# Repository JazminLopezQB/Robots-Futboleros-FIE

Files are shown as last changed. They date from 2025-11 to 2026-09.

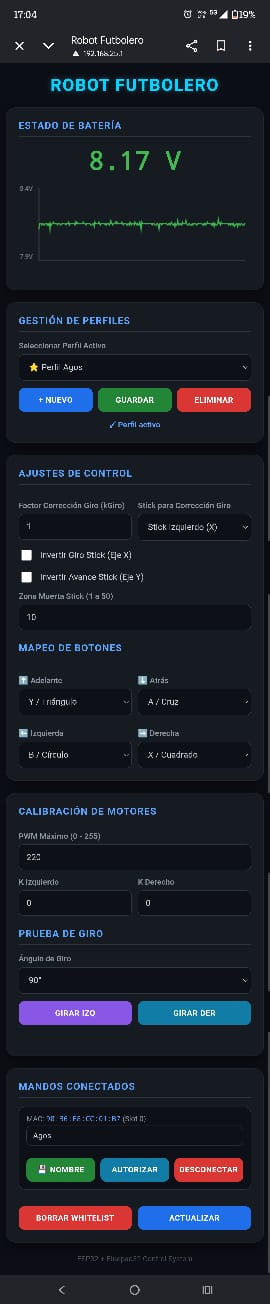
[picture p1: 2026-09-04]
Código_Agos_BLUEPAD32/APyWEB_Actual.jpeg

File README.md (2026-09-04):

# Robots Futboleros de la FIE

---
## Instrucciones de Uso con CÓDIGO VIEJO

### Conectar Mando Bluetooth a Robot

#### 1) Conseguir la MAC Adress de la ESP usada:
  1. Activar el Bluetooth de la ESP.
  2. Descargar la siguiente aplicación en el celular.
  3. Vincularse desde el celular a la ESP con Bluetooth.
  4. Abrir la aplicación y dirigirse a la sección de dispositivos.
  5. En dicha sección debería aparecer la ESP con su MAC Adress.

#### 2) Grabar la MAC Adress correcta al mando:
  1. Descargar e instalar SixaxisPairTool.
  2. Abrir la aplicación y conectar el mando a la computadora mediante un cable USB.
  3. Si es la primera vez que se conecta el mando, se descargarán e instalarán los drivers adecuados.
  4. Una vez finalizado el proceso, en la aplicación meter la MAC Adress de la ESP y darle a actualizar.
  5. Corroborar.

### Mantenimiento de Baterias

- Para controlar el nivel de las baterías:
  - Medir con multimetro en los pines VCC y GND de los puentes H o en la bornera en caso de tener una.
  - La tensión minima es de 6,5V y la máxima de 8,4V

- Para mantener:
  - En caso de que la tensión sea mínima, retirar las baterias y cargar adecuadamente.
  - Al reponer las baterias, reforzar y homologar.

### Tips Generales

- En caso de que el robot sufra una contusión y se reinicie, presionar el boton de conexión de el mando para reestablecer el enlace entre ambos.
- Presionando el panel tactil de los mandos de PS4 se puede determinar su nivel de bateria según cuanto vibren.

---
---
## Bluepad32 ESP32

**Links Útiles:** ^43a2ae
- Mandos soportados: https://bluepad32.readthedocs.io/en/latest/supported_gamepads/
- Emparejar un solo mando: https://bluepad32.readthedocs.io/en/latest/FAQ/#how-to-pair-just-one-controller-to-one-particular-board

> [!Check] Ventajas sobre el PS4 Controller. 
>
| | Bluepad32 |  PS4 Controller |
| :---: | :---: | :---: |
| **Compatibilidad** | Genérico | Sólo para PS4 |
| **Complejidad de emparejamiento** | Fácil y de muchos recursos | Complejo |
| **Mantenimiento** | Actualizaciones constantes | Librería obsoleta |

> Debemos agregarle verificación / autenticación. Se explica en el último link, pero se debe adicionar la mejora de la selección del mismo posiblemente con web server.

***
***
## TIPS e INFO:

**Placa V3 usada en la Bestia 2.0 y la Bella:** 
> La placa posee diversos arreglos, entre ellos posee la conexión por puente del ENABLE con 3v3; y otro puente que va del regulador de 5V a Vin, además, el regulador se cambió ya que el conseguido fue de 3v3 por error y se consiguió uno de inserción a ultimo momento de pinaje distinto al SMD. 

> [!Important] La ESP es de 36 pines por confusión, lo que cambia el pinaje del código. 

> [!Check] Mejoras y comodidades observadas:
> - Los conectores facilitan la conexión y desconexión rápida y fácil de los motores, la batería y el LED. 
> - Los sockets son cruciales para cambio de componentes. 
> - El capacitor de carga permitió menos desconexión por choques pese a tener que homologar el portapilas.

**Comentarios y Cambios por futbolero en el Código:** ^925762
1. **Pinaje de las Placas y motores:**

| Pines | Bestia 1.0 | Bestia 2.0 | Bella |
| --- | --- | --- | ----- |
| Atras_Izq | 25 | 25 | 26 |
| Adelante_Izq | 26 | 26 | 25 |
| Atras_Der | 18 | 14 | 12 |
| Adelante_Der | 21 | 12 | 14 |
| PIN_LED 2 | 13 | 2 | 2 |
2. **Funciones:** para la Bestia 1.0, los pwm del movimiento se invierte en suma y resta; como tambien la funcion de manejo de botones en izquierda y derecha. 
3. **WIFI e IP:** cambiar en el código los nombres y direcciones por robot para evitar confusión.

| Robot | IP | SSID |
| --- | --- | --- |
| Bestia 1.0 | 192.168.23.1 | Robot-Bestia1.0 |
| Bestia 2.0 | 192.168.24.1 | Robot-Bestia2.0 |
| Bella | 192.168.25.1 | Robot-Bella |
> [!Important] La contraseña para todos es "Fulbo123".

**Funciones de la Página WEB:** ^1c89af
> Permite visualizar y autorizar la conexión de mandos de forma remota, y uno a la vez; como así el cambio de variables como el ángulo de giro, PWM y constantes de ajuste de los motores durante los dos minutos que se crea el access point tra prender la ESP32.

**Manejo del ROBOT:** 

| Botón | Función |
| --- | --- |
| Palanca Derecha | Dirección |
| Palanca Izquierda | - |
| Flechas arriba y abajo | Aumento y disminución de velocidad |
| Botones A Y B X | Manejo de dirección precisa |
| R1 | Turbo |
| R2 | Giro Derecha |
| L2 | Giro Izquierda |
| Menú (+) | Prende el AP para calibrar variables |
| Select (-) | Apaga el AP para calibrar variables  |

**Baterías:** 
> Se observó que las mismas ofrecían duración de 2 partidas contra robots de poca potencia; sin embargo para la batalla contra robots del estilo de PhobosyDeimos baterías con 2 o 3 partidas ya eran insuficientes para empujar la potencia de los robots. 

> [!Check] Mejora con las Baterías:
> - Conseguir baterías LiPo e investigar la carga, duración y conexión en una nueva versión de placa.
> - Chequear el portapilas para:
> 	- Evitar homologación constante por desconexión de mando.
> 	- Fácil acceso para cargar baterías o recambio de las pilas. 

**Conexión del mando:** 
1. Prender el robot con la ESP32. 
2. Abrir desde el dispositivo deseado la conexión WIFI y seleccionar aquel cuyo SSID sea el del robot correspondiente. 
3. Establecida la conexión del Access Point (que dura 2minutos), ingresar a la IP del robot.
4. Prender el mando Bluethoot genérico.
5. Una vez que la ESP lo detecta, la pagina web muestra la mac del mando conectado, pero no permite el manejo del robot hasta autorizarlo.
6. El mando autorizado queda guardado en una lista, y en caso de querer olvidarlo para conectar otro se debe acceder nuevamente al access point y borrar la whislist. 

> [!Info] Para mandos específicos chequear el link de compatibilidad y conexión. 

**Requerimientos para cargar el código:** 
1. Instalar Arduino IDE V2. 
2. Abrir uno de los archivos del código dentro de la misma carpeta ya que de esa manera se compilan juntos y se abren en distintas pestañas.
3. Descargar la placa en Boards de *esp32_bluepad32 by Ricardo Quesada* - V4.1.0.
   https://gitlab.com/ricardoquesada/bluepad32
4. Descargar la librería:
	- BLE-Gamepad-Client by Tomasz Bekas - V0.12.1. 
	- ESP32-BLE-GAMEPAD by IemmingDev - V0.7.3.
5. Conectar la esp vía USB a la PC/Notebook. 
6. Seleccionar la placa DOIT ESP32 DEVKIT V1 - esp32_bluepad32 en el puerto adecuado y detectado en la conexión.
7. Cargar el código (con la flechita).

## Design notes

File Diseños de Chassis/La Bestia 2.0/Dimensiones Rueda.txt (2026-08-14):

medidas de la rueda:espesor del exterior 3mm

diametro de la parte plástica de la rueda 26mm

altura de los grip silicona 1.5mm
ancho del cuadrado de los grip silicona 3x3 mm

ancho de la rueda 30 mm

diámetro total de la rueda 35mm

Distancias al piso:

La bestia:2.3

La bestia 2.0:2.78

agujero de agarre a base pala

26.2 alto

43 largo

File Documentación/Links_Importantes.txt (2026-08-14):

Links importantes para robot futbolista

chassis:
1.https://grabcad.com/library/robot-soccer-amateur-15x15-1
2.https://grabcad.com/library/robot-soccer-amateur-1
3.https://grabcad.com/library/robot-soccer-4
4.https://grabcad.com/library/robot-ulalu-soccer-2-1
5.https://grabcad.com/library/robotfutbolpololu14x14-1
6.https://grabcad.com/library/robotfutbolpololu14x14-1
7.https://grabcad.com/library/soccer-pro-2
8.https://cults3d.com/es/modelo-3d/variado/robot-soccer_competencia

control bluetooth joystick:

1.https://www.youtube.com/watch?v=EEViXFoSzww
2.https://www.youtube.com/watch?v=HMlIpmMx_bo
3.https://www.youtube.com/watch?v=Nn53sg2A-YM

explicacion sobre motores:
https://www.youtube.com/watch?v=xJRm8sAObPk

explicacion mecanica de un minisumo:
https://www.youtube.com/watch?v=hNEtaXyMLsM

planos relacionados al pololu:
https://www.thingiverse.com/thing:3090673
https://www.thingiverse.com/thing:3970849

motores pololu:
https://candy-ho.com/producto/micro-motorreductor-pololu-hp-6v-2000rpm-robotica/
baterias:
https://candy-ho.com/producto/bateria-pila-14500-3-7v-1500mah-recargable-lithium/

motores Brushless:
motor brushless 775

pagina de planos y piezas:
https://grabcad.com/library/robot-soccer-amateur-15x15-1

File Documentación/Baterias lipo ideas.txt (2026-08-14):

Paginas para comprar:
-glcompetizione.com
-tavovernahobbyrc.com.ar
-degahobbies.com/
-rc-flash.com.ar

Baterias lipo ideas:

-2200mah: https://www.mercadolibre.com.ar/bateria-lipo-ovonic-3s-111v-2200mah-120c-con-conector-dean/up/MLAU4268648819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

-2200mah: https://www.mercadolibre.com.ar/bateria-lipo-2200mah-111v-50c-con-conector-xt60-urgenex-rc/up/MLAU4429528969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

-2200mah: https://www.mercadolibre.com.ar/lipo-cnhl-black-series-2200mah-111v-3s-30c-conector-xt60/p/MLA2095109822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

-2200mah:https://www.mercadolibre.com.ar/bateria-lipo-cnhl-3s-40c-2200-mah-111-v-ultra-compacta/p/MLA2082704037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

componentes que hay que considerar para la electronica nueva:
https://candy-ho.com/producto/fuente-step-down-dc-dc-mini360-1v-a-17v-1-8a-17x11mm-arduino/

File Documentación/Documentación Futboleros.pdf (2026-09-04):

## Documentación Futboleros Índice Importante:

Links:

Tips e Info:

## Bluepad32 ESP32

Links Útiles:

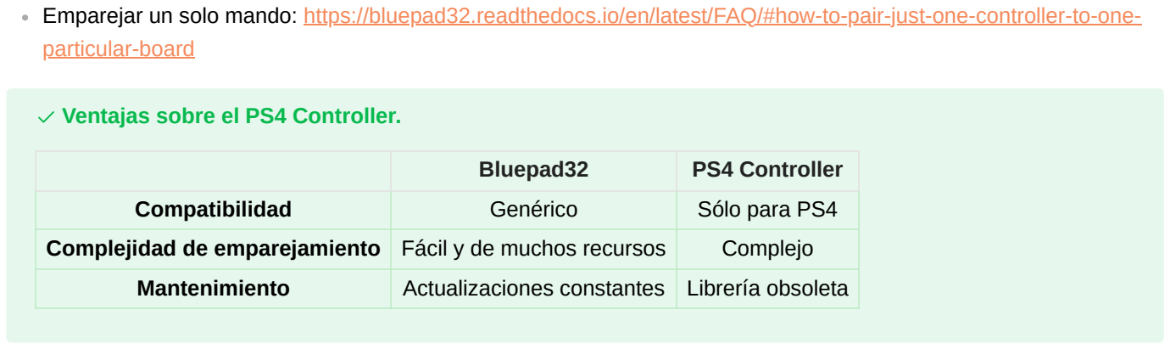
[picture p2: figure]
Emparejar un solo mando: https://bluepad32.readthedocs.io/en/latest/FAQ/#how-to-pair-just-one-controller-to-one- particular-board; Ventajas sobre el PS4 Controller.; Bluepad32; PS4 Controller; Compatibilidad; Genérico; Sólo para PS4; Complejidad de emparejamiento; Fácil y de muchos recursos; Complejo; Mantenimiento; Actualizaciones constantes; Librería obsoleta

Debemos agregarle verificación / autenticación. Se explica en el último link, pero se debe adicionar la mejora de la selección del mismo posiblemente con web server.

## TIPS e INFO:

Placa V3 usada en la Bestia-24 y la Bella:

La placa posee diversos arreglos, entre ellos posee la conexión por puente del ENABLE con 3v3; y otro puente que va del regulador de 5V a Vin, además, el regulador se cambió ya que el conseguido fue de 3v3 por error y se

Links útiles

Placa V3 usada en la Bestia 2.0 y la Bella
Placa V4 usada en la Bestia-24
Comentarios y Cambios por futbolero en el Código Funciones de la Página WEB
Manejo del ROBOT
Baterías
Conexión del mando
Requerimientos para cargar el código Pala
Estrategias
Modo de Juego

Mandos soportados: https://bluepad32.readthedocs.io/en/latest/supported_gamepads/

consiguió uno de inserción a ultimo momento de pinaje distinto al SMD.

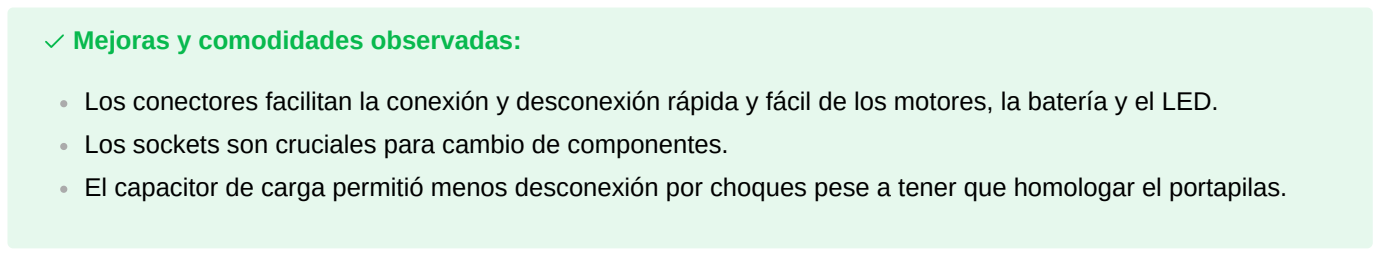
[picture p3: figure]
Mejoras y comodidades observadas:

Placa V4 usada en la Bestia-24:

En su primer versión, la placa posee arreglos provisorios hasta generar la corrección necesaria, entre elllos: el step-down se colocó en diagonal por la inversión de pines y huella; además en la placa, la ficha XT60 hembra no permite el cierre del chasis, por lo que actualmente el arreglo provisorio consta de cables a una ficha hembra XT60 desde la placa y la conexión y desconexión con la LiPo por debajo del robot.

Comentarios y Cambios por futbolero en el Código:

Pines | Bestia 1.0 | Bestia 2.0 | Bella
Atras_Izq | 25 | 25 | 26
Adelante_Izq | 26 | 26 | 25
Atras_Der | 18 | 19 | 12
Adelante_Der | 21 | 18 | 14
PIN_LED 2 | 13 | 2 | 2
Robot | IP | SSID
Bestia 1.0 | 192.168.23.1 | Robot-Bestia1.0
Bestia 2.0 | 192.168.24.1 | Robot-Bestia2.0
Bella | 192.168.25.1 | Robot-Bella

La ESP es de 36 pines por confusión, lo que cambia el pinaje del código.

Sin embargo ya se generó una versión corregida de 30 pines que posee la Bella.

Los conectores facilitan la conexión y desconexión rápida y fácil de los motores, la batería y el LED.
Los sockets son cruciales para cambio de componentes.
El capacitor de carga permitió menos desconexión por choques pese a tener que homologar el portapilas.

Mejoras a realizar:

Corrección de la huella del step-down (inversión de horizontal a vertical) y de su conexión (GND y VCC invertidos).
Vías: las vías actuales poseen poco espacio para la conexión de cables gruesos en el mismo orificio de vía, además que los puentes deberían ser previstos para conexiones que no sean de alimentación.
Adición de un sistema de encendido y apagado de la batería LiPo.
1. Pinaje de las Placas y motores:
2. Funciones: para la Bestia 1.0, los pwm del movimiento se invierte en suma y resta (en el mezclador diferencial); como tambien la funcion de manejo de botones en izquierda y derecha.
3. WIFI e IP: cambiar en el código los nombres y direcciones por robot para evitar confusión.

La contraseña para todos es "Fulbo123".

Funciones de la Página WEB:

Permite visualizar y autorizar la conexión de mandos de forma remota, y uno a la vez; como así el cambio de variables como el ángulo de giro, PWM y constantes de ajuste de los motores durante los dos minutos que se crea el access point tra prender la ESP32. Se adicionó un manejo de perfiles para configurar por comodidad.

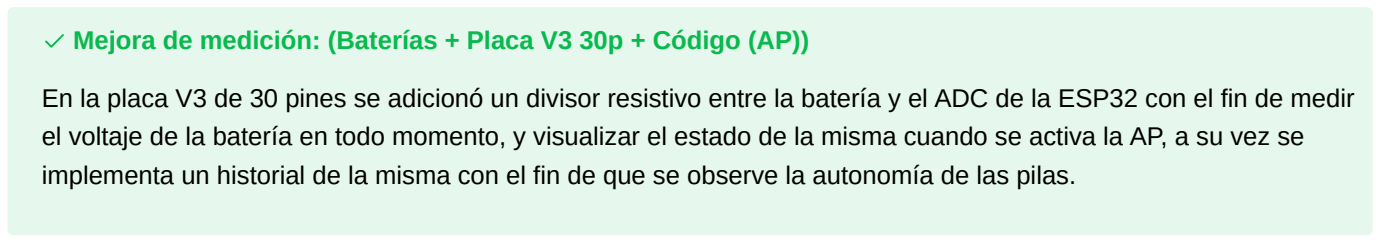
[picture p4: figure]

WEB: funcionalidades y visualización en orden descendete...

Manejo del ROBOT:

Botón | Función
Palanca Derecha | Dirección
Palanca Izquierda | -
Flechas arriba y abajo | Aumento y disminución de velocidad
Botones A Y B X | Manejo de dirección precisa
R1 | Turbo
R2 | Giro Derecha
L2 | Giro Izquierda
Menú (+) | Prende el AP para calibrar variables
Select (-) | Apaga el AP para calibrar variables

Sin embargo recordar que por perfil se peude mapear los botones de movimiento, como así la corrección del turbo con cada palanca.

Baterías:

Se observó que las mismas ofrecían duración de 2 partidas contra robots de poca potencia; sin embargo para la batalla contra robots del estilo de PhobosyDeimos baterías con 2 o 3 partidas ya eran insuficientes para empujar la

Mejora de medición: (Baterías + Placa V3 30p + Código (AP))

En la placa V3 de 30 pines se adicionó un divisor resistivo entre la batería y el ADC de la ESP32 con el fin de medir el voltaje de la batería en todo momento, y visualizar el estado de la misma cuando se activa la AP, a su vez se implementa un historial de la misma con el fin de que se observe la autonomía de las pilas.

Estado de la batería junto a gráfico de hitorial.
Gestión de perfiles junto al selector del mismo (permite generar y eliminar perfiles, o, guardar los cambios realizados en las variables dentro del perfil).
Ajustes de control: se puede ajustar la constante de corrección del giro en turbo y si el mismo se controla con el stick izquierdo o derecho; la inversión o no de los ejes del stick; el mapeo de los botones para el movimiento del robot.
Calibración de Motores: permite ajustar el PWM máximo, como también ajustar la constante de compensación de cada motor (en caso que uno vaya más rápido que el otro lado); además de las pruebas de giro para L2 y R2 (ajustando los grados de giro).
Mandos conectados: permite asignarle un nombre al joystick conectado, con el fin de que en cada conexión, ya que la MAC no varía, se sepa correctamente qué mando fue conectado.

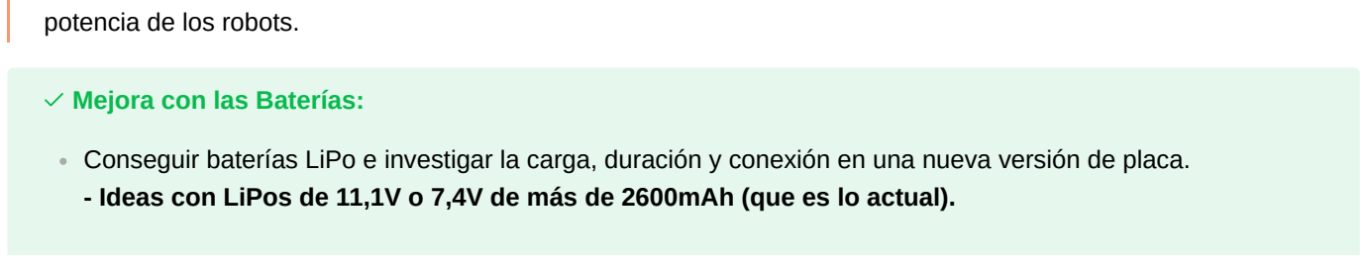
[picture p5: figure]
potencia de los robots.; Mejora con las Baterías:

Conseguir baterías LiPo e investigar la carga, duración y conexión en una nueva versión de placa.
- Ideas con LiPos de 11,1V o 7,4V de más de 2600mAh (que es lo actual).

Conexión del mando:

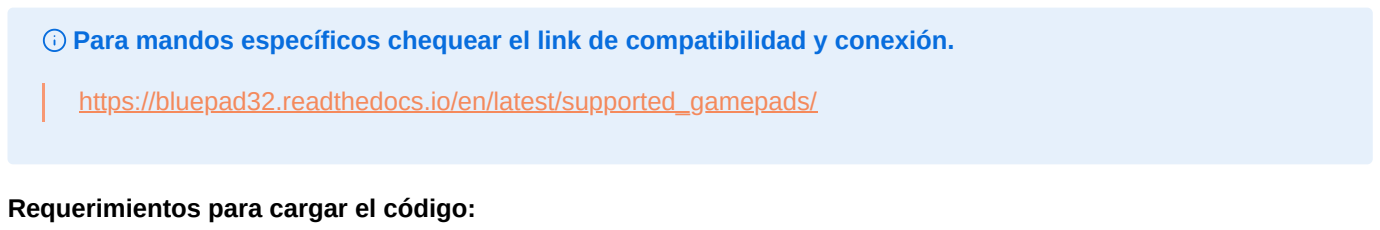
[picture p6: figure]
Requerimientos para cargar el código:; https://bluepad32.readthedocs.io/en/latest/supported_gamepads/

Pala:

Evitar homologación constante por desconexión de mando. Fácil acceso para cargar baterías o recambio de las pilas.

Actualmente la batería LiPo de la Bestia2.0 (el 24) es de 7,4V y 2200mAh con ficha XT60.

1. Prender el robot con la ESP32.
2. Abrir desde el dispositivo deseado la conexión WIFI y seleccionar aquel cuyo SSID sea el del robot correspondiente.
3. Establecida la conexión del Access Point (que dura 2minutos), ingresar a la IP del robot.
4. Prender el mando Bluethoot genérico.
5. Una vez que la ESP lo detecta, la pagina web muestra la mac del mando conectado, pero no permite el manejo del robot hasta autorizarlo.
6. El mando autorizado queda guardado en una lista, y en caso de querer olvidarlo para conectar otro se debe acceder nuevamente al access point y borrar la whitelist.

Para mandos específicos chequear el link de compatibilidad y conexión.

1. Instalar Arduino IDE V2.
2. Abrir uno de los archivos del código dentro de la misma carpeta ya que de esa manera se compilan juntos y se abren en distintas pestañas.
3. Descargar la placa en Boards de esp32_bluepad32 by Ricardo Quesada - V4.1.0. https://gitlab.com/ricardoquesada/bluepad32
4. Descargar la librería:
BLE-Gamepad-Client by Tomasz Bekas - V0.12.1.
ESP32-BLE-GAMEPAD by IemmingDev - V0.7.3.
5. Conectar la esp vía USB a la PC/Notebook.
6. Seleccionar la placa DOIT ESP32 DEVKIT V1 - esp32_bluepad32 en el puerto adecuado y detectado en la conexión.
7. Cargar el código (con la flechita).

Con garras: la pala de Paraná 2025 y la utilizada en la competencia del ITBA 2026, funciona para el agarre y manejo de la pelota como así también para retener al rival.

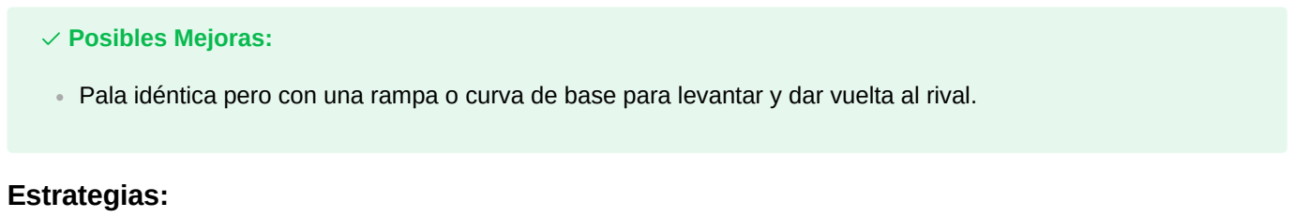
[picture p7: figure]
Estrategias:; Posibles Mejoras:

Pala idéntica pero con una rampa o curva de base para levantar y dar vuelta al rival.

Pared: consiste en rebotar la pelota con la pared para pasar al rival, llevar la pelota al centro y esquivarlo. Centro: permite entre jugadores hacer un rebote como el de pared (es un pase) al centro para meter gol.

Modo de Juego:

Suele funcionar bien uno adelante y uno atrás, mientras uno maneja la jugada, el otro defiende en caso que haya una pelota perdida. Siempre que el defensor esté atento a las estrategias para gol.

Tapadera: que el jugador que no lleva la pelota, marque y se interponga contra el rival que quiere sacarle la pelota, con tal de marcar faltas.

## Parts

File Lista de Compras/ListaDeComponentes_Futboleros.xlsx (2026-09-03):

Prioridad | Cantidad |  | Componente | Precio Unitario | Precio Total | Link de Compra
1 | 3 | unidades | Pila 2200mah 50c 7.4v Lipo | $56240.00 | $168720.00 | https://glcompetizione.com/product/pila-2200mah-50c-7-4v-lipo/ | Glcompetizione
2 | 6 | par hembra macho | Fichas Xt60 Xt-60 Par Macho Y Hembra Lipo | $1531.00 | $9186.00 | https://candy-ho.com/producto/fichas-xt60-xt-60-par-macho-y-hembra-lipo/ | candy ho
3 | 2 | unidades | Fuente Step Down Dc Dc Mini360 1v A 17v 1.8a 17x11mm Arduino | $1373.00 | $2746.00 | https://candy-ho.com/producto/fuente-step-down-dc-dc-mini360-1v-a-17v-1-8a-17x11mm-arduino/ | candy ho
4 | 4 | unidades | Sensor De Energía Corriente Ina219 26v 3.2a Arduino | $3898.00 | $15592.00 | https://candy-ho.com/producto/sensor-de-energia-corriente-ina219-26v-3-2a-arduino/ | candy ho
5 | 2 | x5 | Pack X 5 Resistencia 2512 Smd 1w (0,47) | $3790.00 | $7580.00 | https://articulo.mercadolibre.com.ar/MLA-856693167-pack-x-5-resistencia-2512-smd-1w-elegir-resistencia-_JM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 | ML
6 | 2 | x5 | Pack X 5 Resistencia 2512 Smd 1w (0,22) | $3790.00 | $7580.00 | https://articulo.mercadolibre.com.ar/MLA-856693167-pack-x-5-resistencia-2512-smd-1w-elegir-resistencia-_JM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 | ML
7 | 8 | unidades | Drive Motor Dc Puente H 1.5a 3v A 10v Drv8833 2ch H-bridge | $2465.00 | $19720.00 | https://candy-ho.com/producto/drive-motor-dc-puente-h-1-5a-3v-a-10v-drv8833-2ch-h-bridge/ | candy ho
8 | 10 | unidades | Diodo Schottky 15sq045 15a 45v | $504.00 | $5040.00 | https://candy-ho.com/producto/diodo-schottky-p-celdas-solares-15sq045-i5sq045-15a-45v/ | candy ho
9 | 1 | caja | Tornillo Fresada M3 X 8 Por 500u. Ranura Philips | $14370.06 | $14370.06 | https://www.mercadolibre.com.ar/tornillo-fresada-m3-x-8-por-500u-ranura-philips/up/MLAU3184034189 | Mercado Libre (tornilleria urano)
10 | 1 | caja | Tuerca Hexagonal Metrica M3 X 0,50 Caja Por 500u. | $7687.50 | $7687.50 | https://www.mercadolibre.com.ar/up/MLAU338291441?matt_tool=89488245&pdp_filters=item_id:MLA1707099878 | Mercado Libre (tornilleria urano)
11 | 4 | unidades | Placa ESP32 USB C CH340C Arduino NodeMCU 32S Lua WiFi IOT BT | $9416.00 | $37664.00 | https://candy-ho.com/producto/placa-esp32-usb-c-ch340c-arduino-nodemcu-32s-lua-wifi-iot-bt/ | candy ho
12 | 3 | unidades | Joystick inalámbrico | $47900.00 | $143700.00 | https://www.mercadolibre.com.ar/joystick-inalambrico-compatible-nintendo-switch-2-y-oled-control-pc-gamer-inalambrico-usb-android-steam-dehuka/p/MLA19472403 | ML
13 | 8 | unidades | Motor con Caja Reductora JGA25-370 DC6V 620RPM Nubbeo | $20899.00 | $167192.00 | https://www.nubbeo.com.ar/productos/motor-con-caja-reductora-jga25-370-dc6v-620rpm-nubbeo/ | Nubbeo
14 | 1 | unidades | Pack Lipo a bordo, ProTek 7.4V/2300mAh | $74480.00 | $74480.00 | https://glcompetizione.com/product/pack-lipo-a-bordo-protek-7-4v-2300mah/ | Glcompetizione
15 | 2 | x10 | Placa Virgen Cobre 10x10 Simple Faz Pcb Púlsar Cladex X10u | $24900.00 | $49800.00 | https://www.mercadolibre.com.ar/placa-virgen-cobre-10x10-simple-faz-pcb-pulsar-cladex-x10u/up/MLAU298975188 | ML
16 | 2 | unidades | Contacflux Delta Protector Circuitos Impresos 120gr Flux | $10900.00 | $21800.00 | https://www.mercadolibre.com.ar/contacflux-delta-protector-circuitos-impresos-120gr-flux/up/MLAU271158093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 | ML
17 | 1 | unidades | Máscara Uv Antisoldante Pcb Celulares Relife Uvh 902 Negro | $7300.00 | $7300.00 | https://www.mercadolibre.com.ar/mascara-uv-antisoldante-pcb-celulares-relife-uvh-902-negro/p/MLA72189862 | ML
18 | 1 | unidades | Seda Malla Tela Gasa Serigrafia 54 Hilos Para Schablones | $17600.00 | $17600.00 | https://www.mercadolibre.com.ar/seda-malla-tela-gasa-serigrafia-54-hilos-para-schablones/up/MLAU266751613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 | ML
19 | 1 | unidades | Shablon Bastidor Serigrafia 20x26 47h. | $9000.00 | $9000.00 | https://www.mercadolibre.com.ar/shablon-bastidor-serigrafia-20x26-47h/up/MLAU3631038555 | ML
20 | 1 | unidades | Pintura Aerosol Uso General Smart Paint 350ml /250gr Doble A Color Negro Mate | $6920.00 | $6920.00 | https://www.mercadolibre.com.ar/pintura-aerosol-uso-general-smart-paint-350ml-250gr-doble-a-color-negro-mate/p/MLA25278984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 | ML
TOTAL | 63 |  |  |  | $793677.56

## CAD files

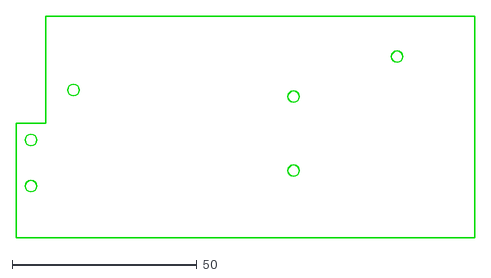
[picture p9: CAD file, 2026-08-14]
Diseños de Chassis/La Bestia 2.0/Archivos de Corte Laser/Pieza lateral.dxf
124.0 x 60.0

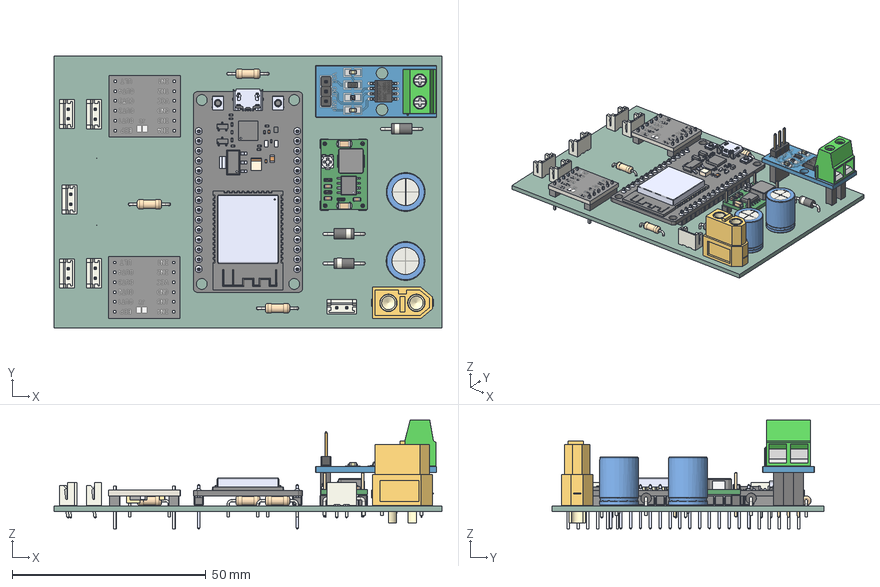
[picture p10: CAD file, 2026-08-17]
Placa_Futboleros/3D's_sobrePlacas/Placa V4.step
100.0 x 70.0 x 28.0 mm
R_Axial_DIN0207_L63mm_D25mm_P1016mm_Horizontal x 3
JST_B2B_EH_A x 6
C_Radial_D100mm_H125mm_P500mm x 2
User Library-SOIC-8 - TEK v1
Resistor 0603 v1 x 3
CAPC0603 v1 x 3
CAPC1206 v1 x 2
EVM-3E v2
PinHeader_1x01_P254mm_Vertical x 4
ESP32-DEVKIT-V1
ACS712_platine_001
IC_ACS712_001
SMD_LED_rot_001
SMD_R_001
SMD_DIODE_0.9mm_002
Pins_3fach_001
SMD_DIODE_0.9mm_001
Velleman_145848_001
PinSocket_1x03_P2.54mm_Vertical
PinSocket_1x01_P2.54mm_Vertical x 2
D_DO-41_SOD81_P10.16mm_Horizontal x 3
XT60 female v5
Placa V4_PCB

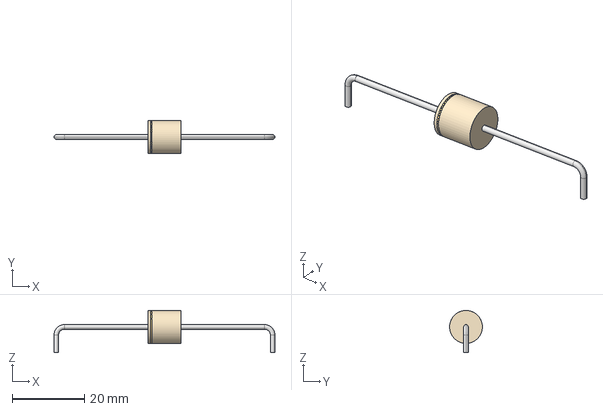
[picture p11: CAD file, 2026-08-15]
Placa_Futboleros/Librerías_Proyecto/Diodo_15sq045/DIODE_15SQ045TR_SMC.step
61.2 x 9.10 x 11.6 mm

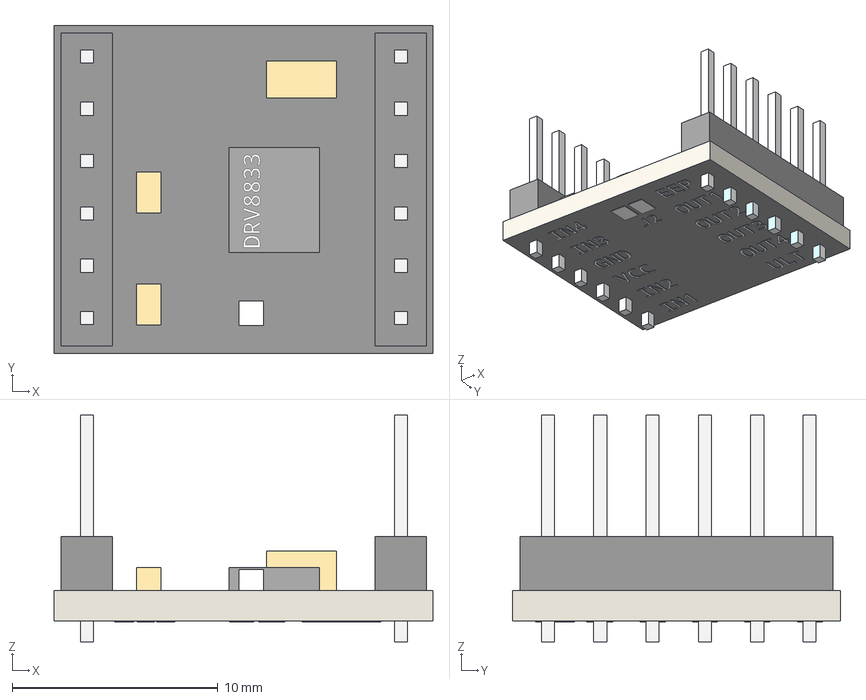
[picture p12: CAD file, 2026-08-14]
Placa_Futboleros/Librerías_Proyecto/DRV8833/HBridgeDRV8833.step
18.4 x 15.9 x 11.0 mm

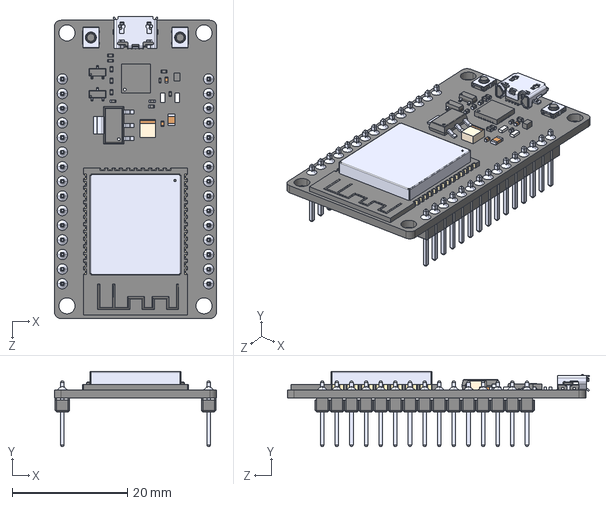
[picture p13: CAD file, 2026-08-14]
Placa_Futboleros/Librerías_Proyecto/ESP32-DEVKIT-V1/ESP32-DEVKIT-V1.step
28.2 x 13.1 x 52.5 mm

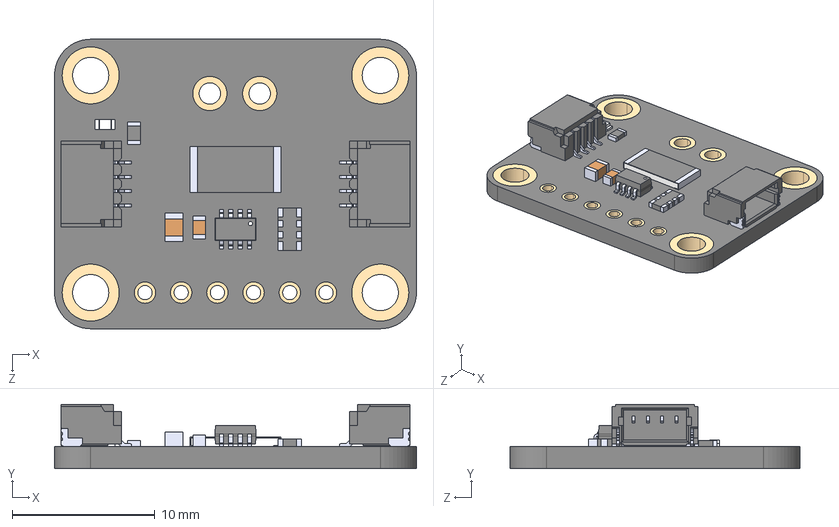
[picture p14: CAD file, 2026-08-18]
Placa_Futboleros/Librerías_Proyecto/INA219/904.step
25.4 x 4.52 x 20.3 mm
INA219BIDCNT_INA219BIDCNT1
SM04B-SRSS-TB(LF)(SN) x 2

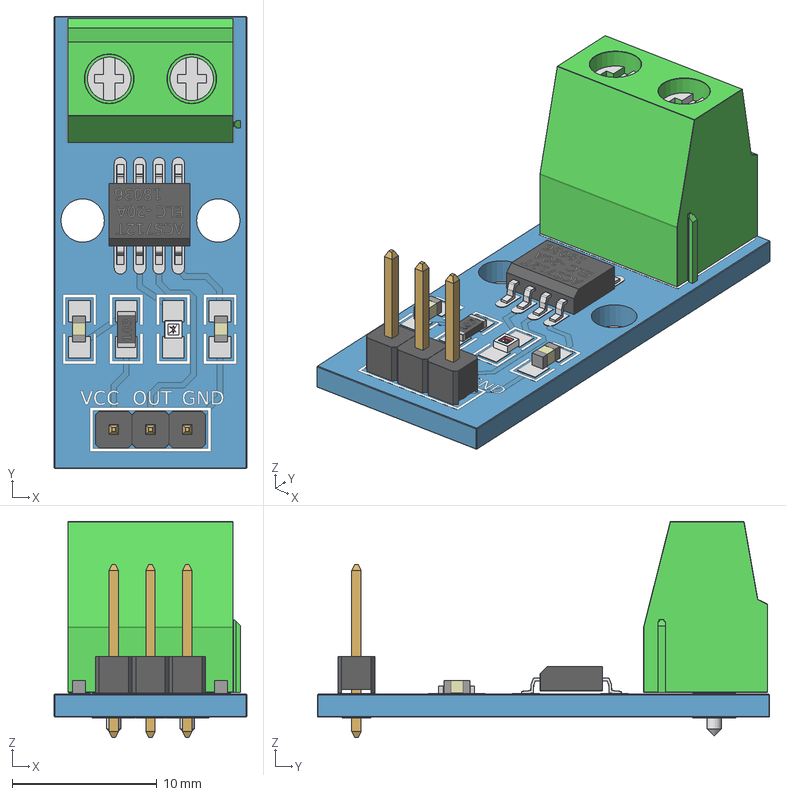
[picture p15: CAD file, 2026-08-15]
Placa_Futboleros/Librerías_Proyecto/SensorCorriente/acs712-arduino-shield-1.snapshot.3/acs712.STEP
13.3 x 31.2 x 14.9 mm
ACS712_platine_001
IC_ACS712_001
SMD_LED_rot_001
SMD_R_001
SMD_DIODE_0.9mm_002
Pins_3fach_001
SMD_DIODE_0.9mm_001
Velleman_145848_001

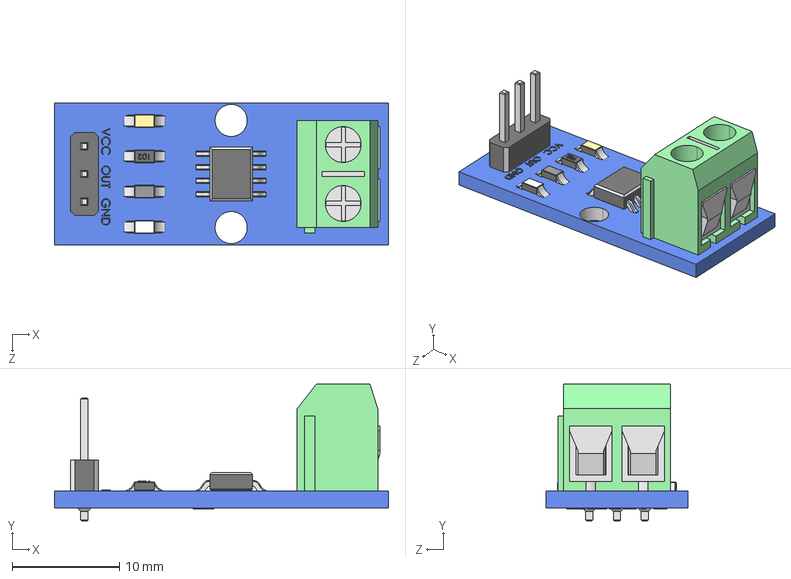
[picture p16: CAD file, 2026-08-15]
Placa_Futboleros/Librerías_Proyecto/SensorCorriente/ACS712.STEP
31.2 x 12.8 x 13.3 mm

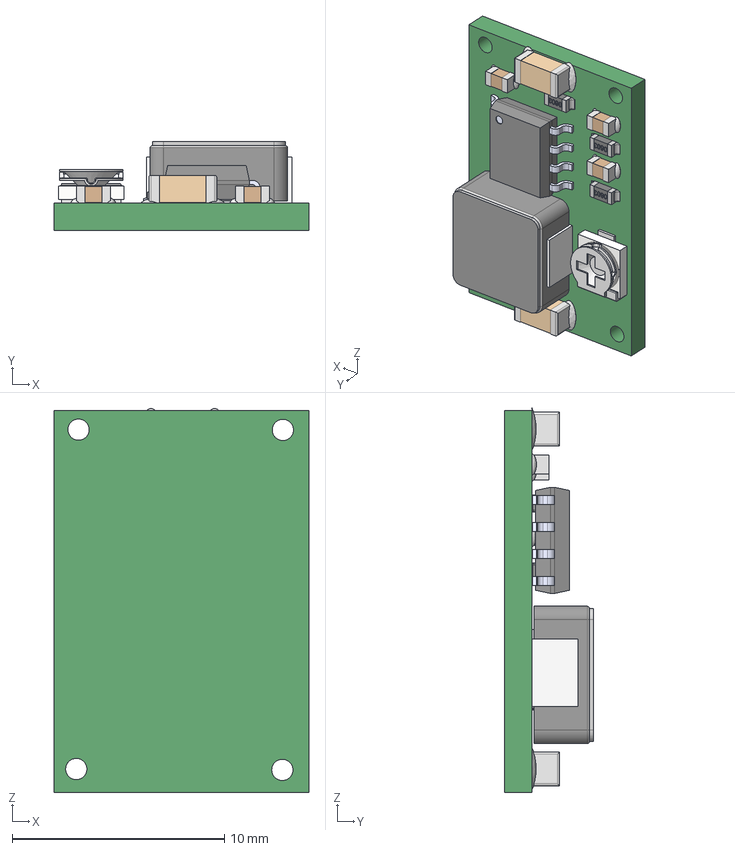
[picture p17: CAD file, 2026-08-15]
Placa_Futboleros/Librerías_Proyecto/StepDown_Mini360/mini360-dc-dc-step-down-module-1.snapshot.2/mini360.step
12.0 x 4.20 x 18.1 mm
User Library-SOIC-8 - TEK
Resistor 0603 x 3
CAPC0603 x 3
CAPC1206 x 2
EVM-3E

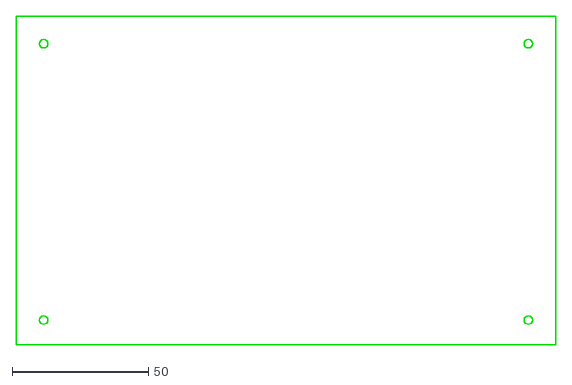
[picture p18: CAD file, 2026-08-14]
Diseños de Chassis/La Bestia 2.0/Archivos de Corte Laser/TapaBestia2.0.dxf
198.0 x 120.5

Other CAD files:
Diseños de Chassis/La Bestia 2.0/PlacaFutbol 2.0/PlacaFutboleros3D_V3.step
Diseños de Chassis/La Bestia 2.0/PlacaMotor/PlacaMotor3D.step
Diseños de Chassis/La Bestia 2.0/STL Impresora Agos/BaseMoldeV2.stl
Placa_Futboleros/3D's_sobrePlacas/L_MontajeMotores/L_MontajeMotores.step
Placa_Futboleros/3D's_sobrePlacas/SoporteLED/SoporteLED-Body.stl
Placa_Futboleros/Librerías_Proyecto/Motor_JGA25-370/3D/JGA25-370 .step
Diseños de Chassis/La Bestia 2.0/STL Impresora Agos/Esquinero3_mir.stl
Placa_Futboleros/3D's_sobrePlacas/PlacaFutboleros3D_V3.step
Diseños de Chassis/La Bestia 2.0/Archivos de Corte Laser/pieza posterior.dxf
Diseños de Chassis/La Bestia 2.0/STL Impresora Agos/Base Bestia 2.0.stl
Diseños de Chassis/La Bestia 2.0/STL Impresora Agos/Esquinero.stl
Diseños de Chassis/La Bestia 2.0/STL Impresora Agos/Esquinero3.stl
Diseños de Chassis/La Bestia 2.0/STL Impresora Agos/Molde_Exterior.stl
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

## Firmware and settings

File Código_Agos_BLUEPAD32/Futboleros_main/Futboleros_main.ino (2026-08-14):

#include <Bluepad32.h>
#include <Arduino.h>
#include "config.h"

#include <WiFi.h>
#include <WebServer.h>
#include <Preferences.h>

// Declaraciones:
void onConnectedController(ControllerPtr ctl);
void onDisconnectedController(ControllerPtr ctl);
void processControllers();
void processControllers();
void giro180Izquierda();
void giro180Derecha();
void iniciarAccessPoint();
void apagarAccessPoint(); 
void controlarAccessPoint();
void cargarConfiguracionMotores();
void escribirPWM();
void movimiento(ControllerPtr ctl, bool turbo);

void leerBateria();
String obtenerHistorialJSON();
void giroIzquierda(int grados);
void giroDerecha(int grados);
//

bool apActivo = false;

// Indica que el AP fue encendido automáticamente al arrancar
bool apTemporal = false;

unsigned long inicioAP = 0;

const unsigned long DURACION_AP = 120000; // 2 minutos

// Estados anteriores de los botones
bool botonStartAnterior = false;
bool botonSelectAnterior = false;

// ================= BATERÍA / ADC =================

#define PIN_BATERIA 32

// Divisor:
// Batería --- 2.7k --- ADC --- 1.5k --- GND

#define RESISTENCIA_SUPERIOR 2700.0
#define RESISTENCIA_INFERIOR 1500.0

float voltajeBateria = 0.0;
float voltajeADC = 0.0;

unsigned long ultimaLecturaBateria = 0;
const unsigned long INTERVALO_BATERIA = 1000; // 1 segundo


// ================= HISTORIAL =================

#define MAX_HISTORIAL 300

float historialVoltaje[MAX_HISTORIAL];
unsigned long historialTiempo[MAX_HISTORIAL];

int indiceHistorial = 0;
int cantidadHistorial = 0;

unsigned long inicioHistorial = 0;

// Variables Globales para Web
WebServer server(80);
Preferences prefs;

// ================= CALIBRACIÓN DE MOTORES =================

uint8_t pwmMaxConfigurado = PWM_MAX;
uint8_t K_IZQ = 0;
uint8_t K_DER = 0;

uint8_t allowedController[6];

bool whitelistEnabled = false;
bool pairingMode = false;

unsigned long pairingStart = 0;
const unsigned long pairingTimeout = 30000;

String authorizedGamepad = "Ninguno";

struct GamepadInfo {

    ControllerPtr ctl;

    String mac;

    String name;

    bool connected;
};

String connectedGamepad = "Ninguno";

GamepadInfo gamepads[BP32_MAX_GAMEPADS];
ControllerPtr myControllers[BP32_MAX_GAMEPADS];


// ========================================================================
// ============================== FUNCIONES ==============================
// ========================================================================
// ==========================================================
// ================== LEER BATERÍA ==========================
// ==========================================================

void leerBateria() {

    int adc = analogRead(PIN_BATERIA);

    // Convertir ADC a tensión en el pin del ESP32
    voltajeADC = (adc / 4095.0) * 3.3;

    // Recuperar tensión real de batería
    voltajeBateria =
        voltajeADC *
        ((RESISTENCIA_SUPERIOR + RESISTENCIA_INFERIOR) /
         RESISTENCIA_INFERIOR);

    // Guardar en historial
    unsigned long tiempo = millis() - inicioHistorial;

    historialVoltaje[indiceHistorial] = voltajeBateria;
    historialTiempo[indiceHistorial] = tiempo;

    indiceHistorial++;

    if (indiceHistorial >= MAX_HISTORIAL) {
        indiceHistorial = 0;
    }

    if (cantidadHistorial < MAX_HISTORIAL) {
        cantidadHistorial++;
    }

    Serial.print("Bateria: ");
    Serial.print(voltajeBateria, 2);
    Serial.print(" V | ADC: ");
    Serial.print(adc);
    Serial.print(" | ADC V: ");
    Serial.println(voltajeADC, 3);
}


// ==========================================================
// ================= HISTORIAL JSON =========================
// ==========================================================

String obtenerHistorialJSON() {

    String json = "[";

    int inicio;

    if (cantidadHistorial < MAX_HISTORIAL) {
        inicio = 0;
    } else {
        inicio = indiceHistorial;
    }

    for (int i = 0; i < cantidadHistorial; i++) {

        int posicion =
            (inicio + i) % MAX_HISTORIAL;

        json += "{";

        json += "\"t\":";
        json += String(historialTiempo[posicion] / 1000.0, 1);

        json += ",";

        json += "\"v\":";
        json += String(historialVoltaje[posicion], 2);

        json += "}";

        if (i < cantidadHistorial - 1) {
            json += ",";
        }
    }

    json += "]";

    return json;
}

// =============== Función para ajustar nivel de velocidad con flechas ===============
unsigned long tiempoUltimoCambio = 0;

void controlVelocidad(bool flecha_arr, bool flecha_abaj) {

  unsigned long ahora = millis();

  if (ahora - tiempoUltimoCambio >= tiempoRebote) { // condicional para evitar el rebote de tiempo

// Si se presiona la flecha de arriba y el nivel actual es menor a la cantidad de niveles...
    if (flecha_arr && nivelActual < cantNiveles-1) {
      nivelActual++; // Aumento el nivel
      factorVelocidad = niveles[nivelActual]; // Inicializo el factor de velocidad dentro del array
      //Serial.printf("Nivel %d | Factor %.2f\n", nivelActual, factorVelocidad);
      tiempoUltimoCambio = ahora; // Guardo el tiempo de cambio
    }

// Si se presiona la flecha de abajo y el nivel actual es mayor a cero...
    if (flecha_abaj && nivelActual > 0) {
      nivelActual--; // Disminuyo el nivel
      factorVelocidad = niveles[nivelActual]; // Inicializo el factor de velocidad dentro del array
      //Serial.printf("Nivel %d | Factor %.2f\n", nivelActual, factorVelocidad);
      tiempoUltimoCambio = ahora; // Guardo el tiempo de cambio
    }
  }
}

// =============== Función para detener los motores ===============
void detenerMotores() {
// Paso valor 0 de PWM a los motores:
    escribirPWM(
        0,  // adelante izquierda
        0,  // atrás izquierda
        0,  // adelante derecha
        0   // atrás derecha
    );

    String sentidoIzq = "DETENIDO";
    String sentidoDer = "DETENIDO";
}

// =============== Función para mover los motores con 255 ===============
void maxima() {
    escribirPWM(
        255,  // adelante izquierda
        0,  // atrás izquierda
        255,  // adelante derecha
        0   // atrás derecha
    );

    String sentidoIzq = "ADELANTE";
    String sentidoDer = "ADELANTE";
}

// =============== Función para mover los motores ===============
void movimiento(ControllerPtr ctl, bool turbo) {

    float x = ctl->axisRX();
    float y = -ctl->axisRY();

    // ==========================================
    // TURBO
    // ==========================================

    if (turbo) {

        // ------------------------------------------
        // R1 mantiene SIEMPRE el avance hacia adelante
        // ------------------------------------------

        // Velocidad base del turbo
        float avance = 255.0;

        // ------------------------------------------
        // La palanca solamente controla el giro
        // ------------------------------------------

        float giro = x / 512.0;

        // Reducimos la influencia de la palanca
        // para que solamente haga una corrección suave.
        giro *= 100.0;

        // Limitar corrección
        giro = constrain(giro, -100.0, 100.0);


        // ------------------------------------------
        // Mezcla:
        //
        // palanca izquierda  -> izquierda más lento
        // palanca derecha    -> derecha más lento
        // palanca centrada   -> ambos 255
        // ------------------------------------------

        float pwmIzq = avance + giro;
        float pwmDer = avance - giro;


        // Limitar a 0-255
        pwmIzq = constrain(pwmIzq, 0, 255);
        pwmDer = constrain(pwmDer, 0, 255);


        // ------------------------------------------
        // Turbo siempre hacia adelante
        // ------------------------------------------

        int adelanteIzq =
            constrain((int)pwmIzq + K_IZQ, 0, 255);

        int adelanteDer =
            constrain((int)pwmDer + K_DER, 0, 255);


        escribirPWM(
            adelanteIzq,
            0,
            adelanteDer,
            0
        );

        return;
    }


    // ==========================================
    // MOVIMIENTO NORMAL
    // ==========================================

    if (abs(x) < ZONA_DRIFT && abs(y) < ZONA_DRIFT) {

        detenerMotores();
        return;
    }


    float normX = x / 512.0;
    float normY = y / 512.0;


    // Mezcla diferencial normal

    float pwmIzq =
        (normY + normX) * 127.0 * factorVelocidad;

    float pwmDer =
        (normY - normX) * 127.0 * factorVelocidad;


    // Movimiento normal respeta PWM_MAX

    pwmIzq = constrain(
        pwmIzq,
        -PWM_MAX,
        PWM_MAX
    );

    pwmDer = constrain(
        pwmDer,
        -PWM_MAX,
        PWM_MAX
    );


    // ==========================================
    // MOTOR IZQUIERDO
    // ==========================================

    int adelanteIzq = 0;
    int atrasIzq = 0;

    int adelanteDer = 0;
    int atrasDer = 0;


    if (pwmIzq >= 0) {

        adelanteIzq =
            constrain(
                (int)pwmIzq + K_IZQ,
                0,
                255
            );

    } else {

        atrasIzq =
            constrain(
                (int)(-pwmIzq) + K_IZQ,
                0,
                255
            );
    }


    // ==========================================
    // MOTOR DERECHO
    // ==========================================

    if (pwmDer >= 0) {

        adelanteDer =
            constrain(
                (int)pwmDer + K_DER,
                0,
                255
            );

    } else {

        atrasDer =
            constrain(
                (int)(-pwmDer) + K_DER,
                0,
                255
            );
    }


    escribirPWM(
        adelanteIzq,
        atrasIzq,
        adelanteDer,
        atrasDer
    );
}

void iniciarAccessPoint(bool temporal) {

    // Si ya está encendido, no hacemos nada
    if (apActivo)
        return;

    WiFi.mode(WIFI_AP);

    // IMPORTANTE:
    // No usamos WiFi.setSleep(false)
    // porque queremos reducir consumo.

    //Bestia 1.0 192.168.23.1
    //Bestia 2.0 192.168.24.1
    //Bella 192.168.25.1

    IPAddress local_IP(192, 168, 25, 1);
    IPAddress gateway(192, 168, 25, 1);
    IPAddress subnet(255, 255, 255, 0);

    WiFi.softAPConfig(local_IP, gateway, subnet);


    bool ok = WiFi.softAP(
        "Robot-Bella",
        "Fulbo123",
        1,
        false,
        1
    );

    if (ok) {

        apActivo = true;
        apTemporal = temporal;
        inicioAP = millis();

        //Serial.println("========== WIFI AP ==========");
        //Serial.println("AP iniciado");
        //Serial.print("IP: ");
        //Serial.println(WiFi.softAPIP());

        if (apTemporal) {
            Serial.println("Modo temporal: 2 minutos");
        } else {
            Serial.println("Modo manual: sin limite de tiempo");
        }

    } else {
        Serial.println("ERROR AL INICIAR AP");
    }
}

void apagarAccessPoint() {

    if (!apActivo)
        return;

    //Serial.println("========== WIFI AP ==========");
    //Serial.println("Apagando Access Point...");

    // Apaga solamente el Access Point.
    // NO apagamos Bluetooth.
    WiFi.softAPdisconnect(false);

    apActivo = false;
    apTemporal = false;

    //Serial.println("Access Point apagado.");
    //Serial.println("Bluetooth permanece activo.");
}

void controlarAccessPoint() {

    if (!apActivo)
        return;

    // Si fue iniciado manualmente con START,
    // no tiene tiempo límite.
    if (!apTemporal)
        return;

    // Si fue iniciado automáticamente al arrancar,
    // dura solamente 2 minutos.
    if (millis() - inicioAP >= DURACION_AP) {
        //Serial.println("2 minutos cumplidos.");
        apagarAccessPoint();
    }
}

void cargarConfiguracionMotores() {

    prefs.begin("config", true);

    PWM_MAX = prefs.getUChar("pwmMax", 220);
    K_IZQ = prefs.getUChar("kIzq", 0);
    K_DER = prefs.getUChar("kDer", 0);
    anguloGiro = prefs.getInt("anguloGiro", 180);

    prefs.end();

    Serial.println("===== CONFIGURACION MOTORES =====");
    Serial.printf("PWM MAX: %d\n", PWM_MAX);
    Serial.printf("K IZQ: %d\n", K_IZQ);
    Serial.printf("K DER: %d\n", K_DER);
}

void guardarConfiguracionMotores() {

    prefs.begin("config", false);

    prefs.putUChar("pwmMax", PWM_MAX);
    prefs.putUChar("kIzq", K_IZQ);
    prefs.putUChar("kDer", K_DER);

    // Guardar también el ángulo
    prefs.putInt("anguloGiro", anguloGiro);

    prefs.end();

    Serial.println("Configuracion de motores guardada.");
    Serial.print("PWM MAX: ");
    Serial.println(PWM_MAX);
    Serial.print("K IZQ: ");
    Serial.println(K_IZQ);
    Serial.print("K DER: ");
    Serial.println(K_DER);
    Serial.print("ANGULO GIRO: ");
    Serial.println(anguloGiro);
}

void escribirPWM(
    int adelanteIzq,
    int atrasIzq,
    int adelanteDer,
    int atrasDer
) {

    pwmActualAdelanteIzq = adelanteIzq;
    pwmActualAtrasIzq = atrasIzq;
    pwmActualAdelanteDer = adelanteDer;
    pwmActualAtrasDer = atrasDer;

    ledcWrite(CH_ADELANTE_IZQ, adelanteIzq);
    ledcWrite(CH_ATRAS_IZQ, atrasIzq);
    ledcWrite(CH_ADELANTE_DER, adelanteDer);
    ledcWrite(CH_ATRAS_DER, atrasDer);
}
// ========================================================================
// ============================== SETUP ==============================
// ========================================================================

void setup() {
  Serial.begin(115200);

    // ================= ADC BATERÍA =================

    pinMode(PIN_BATERIA, INPUT);

    analogReadResolution(12);

    inicioHistorial = millis();

    for (int i = 0; i < MAX_HISTORIAL; i++) {
        historialVoltaje[i] = 0;
        historialTiempo[i] = 0;
    }

  cargarConfiguracionMotores();
// Pines PWM
// Configurar canales PWM:
    ledcSetup(CH_ADELANTE_DER, PWM_FREQ, PWM_RES);
    ledcSetup(CH_ATRAS_DER, PWM_FREQ, PWM_RES);
    ledcSetup(CH_ADELANTE_IZQ, PWM_FREQ, PWM_RES);
    ledcSetup(CH_ATRAS_IZQ, PWM_FREQ, PWM_RES);

// Asociar pines a canales:
    ledcAttachPin(Adelante_Der, CH_ADELANTE_DER);
    ledcAttachPin(Atras_Der, CH_ATRAS_DER);
    ledcAttachPin(Adelante_Izq, CH_ADELANTE_IZQ);
    ledcAttachPin(Atras_Izq, CH_ATRAS_IZQ);

    pinMode(PIN_LED, OUTPUT);
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
void loop() {
        // ================= BATERÍA =================

    if (millis() - ultimaLecturaBateria >= INTERVALO_BATERIA) {

        ultimaLecturaBateria = millis();

        leerBateria();
    }

    controlarAccessPoint();

    if (apActivo) {
        server.handleClient();
    }

    bool dataUpdated = BP32.update();

    if (dataUpdated)
        processControllers();

    // Se recorre la lista de mandos conectados, y si hay uno conectado y está enviando información: 
    for (auto ctl : myControllers) {

        if (!ctl || !ctl->isConnected() || !ctl->hasData())
            continue;

        // 🔥 CAMBIO CLAVE: bloqueo si no está autorizado
        if (!isControllerAllowed(ctl))
            continue;            

        // ================= CONTROL DEL ACCESS POINT =================
        // ================= CONTROL MANUAL DEL AP =================

        // START → encender AP permanentemente
        bool botonStart = ctl->miscStart();

        if (botonStart && !botonStartAnterior) {
            //Serial.println("START -> Encendiendo AP");
            iniciarAccessPoint(false);
        }

        botonStartAnterior = botonStart;

        // SELECT → apagar AP
        bool botonSelect = ctl->miscSelect();

        if (botonSelect && !botonSelectAnterior) {
            //Serial.println("SELECT -> Apagando AP");
            apagarAccessPoint();
        }

        botonSelectAnterior = botonSelect;

            // Booleano para detectar si se detectó los botones para subir y bajar la velocidad
            // sabiendo también si antes se presionó o no para que no haya efecto rebote.
            static bool prevY = false;
            static bool prevA = false;

            bool y = ctl->dpad() & DPAD_UP; // subir
            bool a = ctl->dpad() & DPAD_DOWN; // bajar

            // Si se apretó un botón, y antes no estaba apretado, entonces le envía a la función para controlar la velocidad, 
            // el botón correspondiente en 'true'.
            if (y && !prevY) {
                controlVelocidad(true, false);
            }
            if (a && !prevA) {
                controlVelocidad(false, true);
            }

            // Se actualizan el estado previo del botón:
            prevY = y;
            prevA = a;
            // ================= CONTROL POR BOTONES =================

            antiReboteTriang(ctl);
            antiReboteCruz(ctl);
            antiReboteCirc(ctl);
            antiReboteCuad(ctl);


            // ================= CONTROL POR STICK =================

            bool botonMovimiento =
                ctl->y() ||
                ctl->a() ||
                ctl->b() ||
                ctl->x();


            static unsigned long ultimoIzquierda = 0;
            if (ctl->brake() && millis() - ultimoIzquierda > tiempoRebote) {
                giroIzquierda(anguloGiro);
                ultimoIzquierda = millis();
            }
            
            static unsigned long ultimoDerecha = 0;
            if (ctl->throttle() && millis() - ultimoDerecha > tiempoRebote) {
                giroDerecha(anguloGiro);
                ultimoDerecha = millis();
            }

            //Si apreto R1, entonces se activa el turbo y los motores de adelante aceleran en línea recta a todo lo que da el PWM
            bool turbo = ctl->r1();
    
            //Serial.printf("Botones: %2X:%2X:%2X\n", ctl->brake(), ctl->throttle(), ctl->r1());
            
            if (!botonMovimiento) { 
                movimiento(ctl, turbo); 
            }
        }

    delay(1);
}

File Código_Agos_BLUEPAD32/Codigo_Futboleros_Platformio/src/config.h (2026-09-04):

#pragma once

// LIBRERÍAS
#include <Arduino.h>
#include <stdint.h>
#include <Preferences.h>
#include <WebServer.h>
#include <Bluepad32.h>

// Corrección del drift
#define ZONA_DRIFT 10

// PINES DE MOTORES
#define Atras_Izq 25
#define Adelante_Izq 26

#define Atras_Der 19
#define Adelante_Der 18

// Ajustes - Recordatorio:
    // Bestia 2.0 - 25 26 19 18
    // Bella 26 25 21 18
    // Bestia tranqui 25 26 21 18

    // Las IP's:
        //Bestia 1.0 192.168.23.1
        //Bestia 2.0 192.168.24.1
        //Bella 192.168.25.1
    
    // En la función movimiento, en la mezcla diferencial: 
        // Tener en cuenta que para la Bestia 1.0 y versiones anteriores puede que 
        // haya que invertir los signos de pwmIzq y pwmDer. Se cambia lo de abajo pero donde está implementado
        
        /*
        float pwmIzq = (normY + normX) * 127.0 * factorVelocidad;
        float pwmDer = (normY - normX) * 127.0 * factorVelocidad;
        */
    
        // También tener en cuenta que para esas versiones, también hay que cambiar 
        // los izq y der del manejo con botones. 

// PIN BATERÍA
#define PIN_BATERIA 32

// Valores del divisor resistivo del ADC
#define RESISTENCIA_SUPERIOR 2700.0
#define RESISTENCIA_INFERIOR 1500.0

// LED
#define PIN_LED 2 // 13

// HISTORIAL
#define MAX_HISTORIAL 300

// PWM - Canales, freq, resolución
#define CH_ADELANTE_DER 0
#define CH_ATRAS_DER 1

#define CH_ADELANTE_IZQ 2
#define CH_ATRAS_IZQ 3

#define PWM_FREQ 20000
#define PWM_RES 8

// ESTRUCTURA DEL GAMEPAD
struct GamepadInfo { ControllerPtr ctl; String mac; String name; bool connected; };

// Definición de VARIABLES -----------------------

// PWM
extern uint8_t PWM_MAX;
extern float factorVelocidad;
extern int nivelActual;
extern const int cantNiveles;
extern const float niveles[];

// TIEMPOS
extern int tiempoGiro180;
extern int tiempoCarga;
extern int tiempoGolpe;
extern const unsigned long tiempoRebote;
extern int anguloGiro;

// CONSTANTES DE MOTORES
// Permite realizar una corrección de los motores,
// por ejemplo si uno va más potente que el otro. 
extern uint8_t K_IZQ;
extern uint8_t K_DER;

// PWM ACTUAL
// Permite luego en la web, actualizar los valores
// de PWM. 
extern int pwmActualAdelanteIzq;
extern int pwmActualAtrasIzq;
extern int pwmActualAdelanteDer;
extern int pwmActualAtrasDer;

// MANDOS
extern GamepadInfo gamepads[BP32_MAX_GAMEPADS];
extern ControllerPtr myControllers[BP32_MAX_GAMEPADS];
extern bool whitelistEnabled;
extern uint8_t allowedController[6];
extern bool pairingMode;
extern unsigned long pairingStart;
extern const unsigned long pairingTimeout;
extern String authorizedGamepad;
extern String connectedGamepad;

// PREFERENCES
extern Preferences prefs;

// ACCESS POINT
extern bool apActivo;
extern bool apTemporal;
extern unsigned long inicioAP;
extern const unsigned long DURACION_AP;

// BOTONES
// Son los botones para prender y apagar
// el access point.
extern bool botonStartAnterior;
extern bool botonSelectAnterior;

// BATERÍA - Lectura ADC
extern float voltajeBateria;
extern float voltajeADC;
extern unsigned long ultimaLecturaBateria;
extern const unsigned long INTERVALO_BATERIA;

// HISTORIAL DE BATERÍA
extern float historialVoltaje[MAX_HISTORIAL];
extern unsigned long historialTiempo[MAX_HISTORIAL];
extern int indiceHistorial;
extern int cantidadHistorial;
extern unsigned long inicioHistorial;

// CALIBRACIÓN
extern uint8_t pwmMaxConfigurado;

// WEB SERVER
extern WebServer server;

// Estructuras y variables para el manejo de perfiles de configuración en la web:
// IDs de Botones soportados para mapeo
enum BotonAccion {
    BOTON_NINGUNO = 0,
    BOTON_Y = 1,       // Triángulo / Y
    BOTON_A = 2,       // Cruz / A
    BOTON_B = 3,       // Círculo / B
    BOTON_X = 4,       // Cuadrado / X
    BOTON_L1 = 5,
    BOTON_R1 = 6,
    BOTON_L2 = 7,
    BOTON_R2 = 8
};

struct PerfilConfig {
    char nombre[30];
    int pwmMax;
    int kIzq;
    int kDer;
    int anguloGiro;
    bool invertirEjeX;
    bool invertirEjeY;
    int zonaMuerta;
    int btnAdelante;
    int btnAtras;
    int btnIzq;
    int btnDer;
    
    // 📍 NUEVOS CAMPOS:
    float kGiro;      // Multiplicador/Constante para la corrección del turbo (ej. 0.5 a 2.0)
    int stickGiro;    // 0 = Stick Izquierdo, 1 = Stick Derecho
};

extern int perfilActualID;
extern int totalPerfilesGuardados;

extern PerfilConfig perfilActivo;
extern int perfilActualID;

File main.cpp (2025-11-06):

codigo main robot futbolero
/*
Comentarios: (1) ajustar las variables "duracion", "intensidad", "niveles", "tiempoRebote", "tiempoGiro180", "tiempoCarga", "tiempoGolpe",
(2) pensar si cambiar los delay() de las 4 estrategias por millis()
*/

#include <PS4Controller.h>

// Pines físicos conectados a los DRV8833
#define IN2_L 18    // Atrás izquierda
#define IN1_L 21    // Adelante izquierda
#define IN2_R 25    // Atrás derecha
#define IN1_R 26    // Adelante derecha
#define PIN_LED 13  // LED

// Configuración PWM
#define PWM_FREQ 20000  // Frecuencia en Hz
#define PWM_RES 8       // Resolución en bits (0–255)

// Variables para control de velocidad
float factorVelocidad = 2.0;                  // Factor multiplicador de velocidad (inicial: máxima)
int nivelActual = 2;                          // Nivel actual (2 = velocidad máxima)
const float niveles[3] = { 1.5, 1.65, 2.0 };  // Factores de velocidad por nivel (bajo, medio, alto)

// Variables para tiempos
int tiempoGiro180 = 685;  // Tiempo que tarda en girar 180°
int tiempoCarga = 300;    // Duración del retroceso en ms
int tiempoGolpe = 300;    // Duración del golpe en ms

// Corrección de PWM al motor derecho (IN1_R y IN2_R)
// Sale con Fritas tiene K = 10
// Chispitas tiene K = 0
  int K = 0;

//--------------------------------------------------------------------------------------------------------------------------------------------------------------------------------------------------

// Función para ajustar el nivel de velocidad con flechas arriba y abajo (las estrategias no se ven afectadas por esta función)
unsigned long tiempoUltimoCambio = 0;    // Marca de tiempo del último ajuste
const unsigned long tiempoRebote = 200;  // Tiempo mínimo entre ajustes (ms)

void controlVelocidad(bool subir, bool bajar) {
  unsigned long ahora = millis();
  if (ahora - tiempoUltimoCambio >= tiempoRebote) {
    if (subir && nivelActual < 2) {
      nivelActual++;
      factorVelocidad = niveles[nivelActual];
      Serial.printf("Nivel %d | Factor %.2f\n", nivelActual, factorVelocidad);
      tiempoUltimoCambio = ahora;
    }

    if (bajar && nivelActual > 0) {
      nivelActual--;
      factorVelocidad = niveles[nivelActual];
      Serial.printf("Nivel %d | Factor %.2f\n", nivelActual, factorVelocidad);
      tiempoUltimoCambio = ahora;
    }
  }
}

// Función para detener los motores
void detenerMotores() {
  ledcWrite(IN1_R, 0);
  ledcWrite(IN2_R, 0);
  ledcWrite(IN1_L, 0);
  ledcWrite(IN2_L, 0);
}

// Función de desplazamiento vectorial y rotación simultánea
void movimiento() {
  int pwm = 0;
  int pwmDer = 0;
  int pwmIzq = 0;

  // Lectura del joystick derecho en X e Y
  int ejeX = PS4.RStickX();  // -127 a 127
  int ejeY = PS4.RStickY();  // -127 a 127

  // Zona muerta
  if (abs(ejeX) < 10 && abs(ejeY) < 10 && abs(PS4.LStickX()) < 10) {
    detenerMotores();
    return;
  }

  // Normalización
  float normX = ejeX / 127.0;
  float normY = ejeY / 127.0;

  // Ángulo y magnitud
  float magnitud = constrain(sqrt(normX * normX + normY * normY), 0.0, 1.0);
  float angulo = atan2(normY, normX);  // -π a π
  pwm = constrain(127 * magnitud * factorVelocidad, 180, 232);
  // --- entrada: angulo en radianes (-PI..PI), pwm ya calculado ---
  // Queremos picos en:  0° (izq), 90° (ambos), 180° (der), 270° (ambos negativos)
  // Usamos cos como base y combinaciones para tener los efectos deseados.

  // convertir theta a [0,2PI)
  float theta = angulo;
  if (theta < 0) theta += 2.0f * PI;

  // usar versiones float de cos y max
  float pico0 = fmaxf(0.0f, cosf(theta - 0.0f));
  float pico90 = fmaxf(0.0f, cosf(theta - PI / 2.0f));
  float pico180 = fmaxf(0.0f, cosf(theta - PI));
  float pico270 = fmaxf(0.0f, cosf(theta - 3.0f * PI / 2.0f));

  // Esto crea lóbulos positivos alrededor de cada punto.
  // Queremos que en 90° y 270° ambos motores tengan magnitud, en 0° sólo izq, en 180 sólo der.
  // Construimos magnitudes (positivo) y luego aplicamos signo según adelante/atrás.

  float magIzq = 0.0f;
  float magDer = 0.0f;

  // combinar lóbulos para obtener la forma deseada
  magIzq = pico90 + pico0 + pico270;
  magDer = pico90 + pico180 + pico270;

  // ajustar pesos relativos: en 90 queremos ambos fuertes (ya suman pico90); en 270 queremos ambos negativos:
  // para 270 detectamos retroceso por el seno (o por theta) y aplicamos signo negativo
  // normalizamos magnitudes para que la mayor valga 1
  float fmax = max(magIzq, magDer);
  if (fmax <= 0.0f) fmax = 1.0f;
  magIzq /= fmax;
  magDer /= fmax;

  // definir signo (adelante/atrás) según componente Y original (normY) o según ángulo
  // mejor usar sin(angulo) para dirección continua: sin(theta) >0 => hacia adelante (90), <0 => atrás (270)
  float sentido = sin(angulo);  // >0 adelante, <0 atrás

  // convertir mag a valores con signo entre -1 y 1; si querés permitir giro en sitio (motores opuestos),
  // entonces para ángulos cercanos a 0 o 180 el otro motor debe ser 0 (ya lo logramos con combinación).
  float outIzq = magIzq * (sentido >= 0 ? 1.0f : -1.0f);
  float outDer = magDer * (sentido >= 0 ? 1.0f : -1.0f);

  // escalar al PWM seguro
  float pwmIzqF = outIzq * pwm;
  float pwmDerF = outDer * pwm;

  // aplicar a los H-bridge (manteniendo tu lógica de sentido con normY si preferís)
  if (pwmIzqF >= 0) {
    ledcWrite(IN1_L, (int)round(constrain(pwmIzqF, 0, 232)));
    ledcWrite(IN2_L, 0);
  } else {
    ledcWrite(IN1_L, 0);
    ledcWrite(IN2_L, (int)round(constrain(-pwmIzqF, 0, 232)));
  }
  if (pwmDerF >= 0) {
    ledcWrite(IN1_R, (int)round(constrain(pwmDerF, 0, 232)) + K);
    ledcWrite(IN2_R, 0);
  } else {
    ledcWrite(IN1_R, 0);
    ledcWrite(IN2_R, (int)round(constrain(-pwmDerF, 0, 232)) + K);
  }

  // Registro
  Serial.printf("Ángulo:%.2f | PWM:%d | PWM_L:%d PWM_R:%d\n", angulo * 180 / PI, pwm, pwmIzq, pwmDer);
}

// Estrategia 1 - giro brusco de 180° a la izquierda
void giro180Izquierda() {
  // Motor izquierdo apagado
  ledcWrite(IN1_L, 0);
  ledcWrite(IN2_L, 0);
  ledcWrite(IN2_R, 0);

  // Motor derecho gira hacia adelante
  ledcWrite(IN1_R, 232 + K);  // PWM calibrado para giro
  delay(tiempoGiro180);   // Tiempo estimado para giro completo
  detenerMotores();       // Detener ambos motores
}

// Estrategia 2 - giro brusco de 180° a la derecha
void giro180Derecha() {
  // Motor derecho apagado
  ledcWrite(IN1_R, 0);
  ledcWrite(IN2_R, 0);
  ledcWrite(IN2_L, 0);

  // Motor izquierdo gira hacia adelante
  ledcWrite(IN1_L, 232);  // PWM calibrado para giro
  delay(tiempoGiro180);   // Tiempo estimado para giro completo
  detenerMotores();       // Detener ambos motores
}
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

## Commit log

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2025-11-10 Primer versión corregida
    Se debe evaluar aún su correcto funcionamiento...
    A su vez se divide al programa en tres archivos para evitar código largo y dificil de leer.
    [Estrategias.ino, ManejoConBotones.ino, main.ino]
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2026-05-21 - Nuevo Código Versión 1
    Se crea el primer nuevo código cuya prueba de conexión y funcionalidad fue correcta. En las próximas versiones
    se buscará un mejor manejo con botones (estrategias, etc), la acotación de la conexión de mandos y
    algunas mejores en ello (como una página para conectar correctamente el mando específico); además
    de la codificación del mismo en VSCode/VSCodium en lugar del IDE de Arduino.
    > Se busca adisionar el uso de la librería BLUEPAD32 con el fin de mayor soporte y
    compatibilidad de mandos bluethoot genéricos.
    > Se subdivide al archivo de código en varios archivos para mayor entendimiento y estructuración.
    >> Recordar agregar la función para encende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
    [Futboleros_Conexion.ino, Futboleros_Estrategias.ino, Futboleros_ManejoBotones.ino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]
2026-05-27 Actualización de Código
    Se adiciona la funcionalidad de seleccionar el mando bluethoot a conectar
    y autorizarlo para poder manejar al futbolero...
    Se crea un servidor, se conecta via wifi a la esp, se abre la página web con la ip y se
    procede a seleccionar, autorizar o desconectar el mando.
    A su vez se corrige la constante para equiparar motores, la cual se debe adicionar a los motores izquierdos.
    > OJO! Recordar que es una primera versión, falta comentarlo y chequear mejoras
    [Futboleros_Conexion.ino, Futboleros_Estrategias.ino, Futboleros_ManejoBotones.ino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]
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2026-06-05 Adición de Diseño de Placa Nueva
    Se diseña una nueva placa, específica para el diseño de los futboleros
    la misma posee para evitar un reset de la ESP32, un capacitor electrolítico
    de 470uF.
    Se debe chequear aún el diseño, la disposición y las huellas, con
    los demás compañeros.
    [HBridgeDRV8833.step, Placa_Futboleros_Nueva.kicad_pcb, Placa_Futboleros_Nueva.kicad_sch]
2026-06-06 Mejoras en la Nueva Placa Futboleros
    Se colocan conectores molex jst en lugar de borneras para conectar motores y batería.
    Se cambia el capacitor electrolítico de 470uF.
    Se crea la placa para soldar a los motores y con conectores
    jst conectar la placa a los molex de la placa maestra
    [JGA25-370 .step, Placa_Futboleros_Nueva.kicad_pcb, Placa_Futboleros_Nueva.kicad_sch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]
2026-06-12 Reorganización de carpetas
    Se reordena algunas carpetas para mayor entendimiento...
    También se adiciona el archivo original con links importantes
    que contienen la información desde donde se empezó este proyecto.
    > Tener en cuenta que algunos links pueden ya no estar disponibles, revisar.
    [HBridgeDRV8833.step, JGA25-370 .step, L_MontajeMotores.FCStd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]
2026-07-01 Nueva Versión de Placa
    Se rediseña la placa para obtener mayor espacio y disposición de elemento
    además de colocar vías que sirvan tanto para puentes como placa doble faz.
    [Placa_Futboleros_Nueva.kicad_sch, Placa_Futboleros_Nueva_(V1).kicad_pcb]
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2026-07-14 Nueva versión de placa futboleros
    Se diseña nuevamente la placa con las dimensiones adecuadas para el chasis
    a su vez se toma el consejo del docente de agrandar el pad de disipación.
    [PlacaFutboleros3D_V2.step, PlacaFutboleros3D_V3.step, Placa_Futboleros_Nueva.kicad_pcb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]
2026-08-07 cambio de nombre problematico
2026-08-08 Nueva versión de Código
    El mismo incluye manejo con botones y comentarios que describen los cambios de pines
    entre futboleros, de forma que se actualice el código cada vez que se cambie de
    robot
    [PlacaFutboleros3D_V3.step, Placa_Futboleros_Nueva.kicad_pcb]
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2026-08-09 Corrección Placa V3 a 30 Pines
    Se corrige la placa de la Versión 3 que fue la planchada y pasada por ácido
    con el fin de usar la ESP32 de 30 pines (como venía usándose) y no por error
    de 36 pines.
    Se corrige a su vez el uso de un 7805 de incersión de fácil adquisición por ejemplo
    en JG Electrónico o Bousa Electrónica, en lugar del ams1117 smd.
    [ESP32-DEVKIT-V1.step, Placa_Futboleros_Nueva.kicad_pcb, Placa_Futboleros_Nueva.kicad_sch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]
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2026-08-10 Adicion archivo soporte LED
    Es el modelo 3D que usamos para agarrar más facilmente el LED
    al chasis de forma que quede perpendicular al mismo y se vea mejor.
    [SoporteLED-Body.stl, SoporteLED.FCStd]
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2026-08-10 Idea e Implementación Futura para Placa 30 pines V3
    Se agrega un divisor resistivo de las baterías al ADC para monitoreo
    y lectura del voltaje de las baterías para mnostrar en la web cuando
    se active el AP; con el fin de también poseer un historial de mediciones
    y calcular la cantidad de partidos.
    También conviene para regular el PWM en función del voltaje
    recibido para mantener la potencia en los motores.
    [Placa_Futboleros_Nueva.kicad_pcb, Placa_Futboleros_Nueva.kicad_sch]
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2026-08-13 Correección Kicad y ADC codigo
    Se agrega adc al codigo y cambio en kicad ya que el NPTH mecanico arruino las redes
    [Placa_Futboleros_Nueva.recovered.2026-08-13_174421.kicad_pcb]
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2026-08-14 Solucion problema nombre de carpeta Platformio
    [Variables.cpp, config.h, funciones_Conexion.cpp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]
2026-08-15 Adicion de librerías y componentes para placa v4
    Se comienza el diseño circuital de la placa V4 de los futboleros
    para luego pasar al esquemático, poseyendo ya los símbolos, huellas
    y 3d posibles.
    [ACS712.STEP, DIODE_15SQ045TR_SMC.step, ESP32-DEVKIT-V1.step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]
2026-08-15 Idea Placa V4 Futboleros
    Se diseña un primer sketch de la placa v4 de los futboleros
    en kicad, la misma contiene todas las mejoras circuitales,
    y pasa a ser un poco mas grande 125mmx60mm (antes 100mmx52mm).
    [ACS712.FCStd, Placa V4.kicad_pcb, Placa V4.kicad_sch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]
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2026-08-16 Actualización de Placa
    Se actualiza la placa V4 para ancho de pistas, y
    corrección de vías debajo de componentes
    [Placa V4.kicad_pcb]
2026-08-17 Actualización placa V4
    Se reacomoda los componentes y pistas para adaptar el tamaño de la placa
    a las placas que poseemos. La placa ahora es de 100mm x 70mm siendo las
    compradas de 100mm x 100mm de forma que entra bien.
    Las poistas anchas de los motores/drivers y las baterías son de 2,2mm
    para una corriente aprox de 7A. El resto son de 1,2mm.
    Se adiciona la impresión de las placas en la carpeta de los PDF's, como
    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
    [Placa V4.kicad_pcb, Placa V4.kicad_sch]
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2026-08-17 Corrección pistas placa V4
    Se achican las pistas que estaban engrosadas popr error.
    Y se vuelve a exportar el pdf para imprimir.
    [Placa V4.kicad_pcb]
2026-08-18 Actualziación placa V4
    Actualizamos sensor de corriente por sensibilidad de medicion
    de ACS172 a INA219 colocando 4 resistencias SMD de 0,22 a 1W
    para soportar mayor corriente a igual resolución.
    Se reacomodan cosas en la placa para colocar dicho módulo.
    [904.step, Placa V4.kicad_pcb, Placa V4.kicad_sch]
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2026-08-18 Correcciones menores de la placa V4
    Sobre espacio entre pistas, entre otros.
    [Placa V4.kicad_pcb, Placa V4.kicad_sch]
2026-08-20 Actualización placa V4
    Se reordenan pistas, se repiensa resistencias smd para x4 de 0,47 ohm
    y se deja más prolija. (Chequeado con Dominici)
    [Placa V4.kicad_pcb, Placa V4.kicad_sch]
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2026-09-03 Actualización de variable de giro
    Se actualiza la variable de giro en turbo para
    un mejor manejo en el saque
    [ListaDeComponentes_Futboleros.xlsx, Placa V4.kicad_pcb, Placa V4.kicad_sch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]
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2026-09-04 Arreglo de readme
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
